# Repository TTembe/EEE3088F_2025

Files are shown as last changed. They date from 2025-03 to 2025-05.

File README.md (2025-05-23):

#  Micro-Mouse Power Subsystem – EEE3088F 2025

This repository contains the schematic, PCB layout, firmware, and documentation for the **Power Subsystem** of a maze-solving Micro-Mouse robot, developed as part of the EEE3088F course at the University of Cape Town.

---

##  Project Overview

This project focuses on the design, implementation, and testing of a compact and efficient **Power Subsystem** for a Micro-Mouse (MM) robot.

The power module is responsible for delivering regulated voltages, safe battery charging, motor power distribution, and real-time monitoring all within a space- and cost-constrained printed circuit board (PCB) footprint. It was developed to integrate seamlessly with the rest of the Micro-Mouse system, which includes processing, sensing, and control subsystems.

This subsystem ensures that all other modules in the robot receive stable power while providing built-in protection, control, and monitoring features. Its design includes features like dual-mode battery charging, USB-C PD negotiation, high-side switching for external loads, and I2C-based current/voltage sensing. 

The design adheres to the full set of requirements for the complete robot. The board is designed for manufacturability via JLCPCB and optimized for both performance and academic assessment.

---

##  Features

-  **Dual Motor Power Support**  
  Powers up to 4 brushed DC motors with reliable bidirectional control  including two high-current auxiliary motors (500mA each).

-  **Intelligent Battery Charging**  
  Automatically charges a single-cell LiPo battery from a 9V input using a selectable current mode: safe slow charge (~200mA) or faster charging (~600mA ±100mA).

-  **Real-Time Power Monitoring**  
  Monitors battery voltage and current in real-time using the INA219 sensor connected to the I²C bus, enabling diagnostics and data logging.

-  **USB-C Power Delivery Integration**  
  Negotiates 9V from compliant USB-C PD sources via the CH224K controller to support flexible charging and system power input.

-  **External Load Control**  
  Includes two high-side load switches for driving external 5V peripherals up to 1A each, with control via GPIO from the main processor.

-  **Precision Voltage Regulation**  
  Provides clean and accurate 3.3V (±5%) and 5V (±5%) rails for digital logic and sensor subsystems, supporting peak currents of up to 1.5A.

-  **Efficient Power Switching**  
  Features a physical ON/OFF switch that disables both 3.3V and 5V rails when inactive, reducing standby battery draw to under 30μA.

-  **Compact PCB Footprint**  
  Fully integrated on a compact 82mm × 60mm 2-layer PCB, designed for modular stacking with the micro-mouse system.

-  **Cost-Effective Design**  
  Uses carefully selected components and efficient routing to stay well within the \$70 total budget limit for the project.

---

## Repository Structure

```bash
├── hardware/
│   ├── PCB_KiCad/             # Schematic and PCB layout (KiCad)
│   ├── Gerber_Files/          # JLCPCB-ready fabrication files
│   └── BOM/                   # Bill of Materials (.xlsx and .tex)
│
├── firmware/
│   ├── PowerControl/          # Firmware for fast charge control via PB4
│   └── INA219_Test/           # Firmware to read INA219 values via I2C
│
├── test_procedures/
│   └── ATP_Documents/         # Detailed Acceptance Test Procedures
│
├── docs/
│   ├── Report_Final.pdf       # Final academic report
│   └── Images/                # System diagrams, PCB renders
│
└── README.md

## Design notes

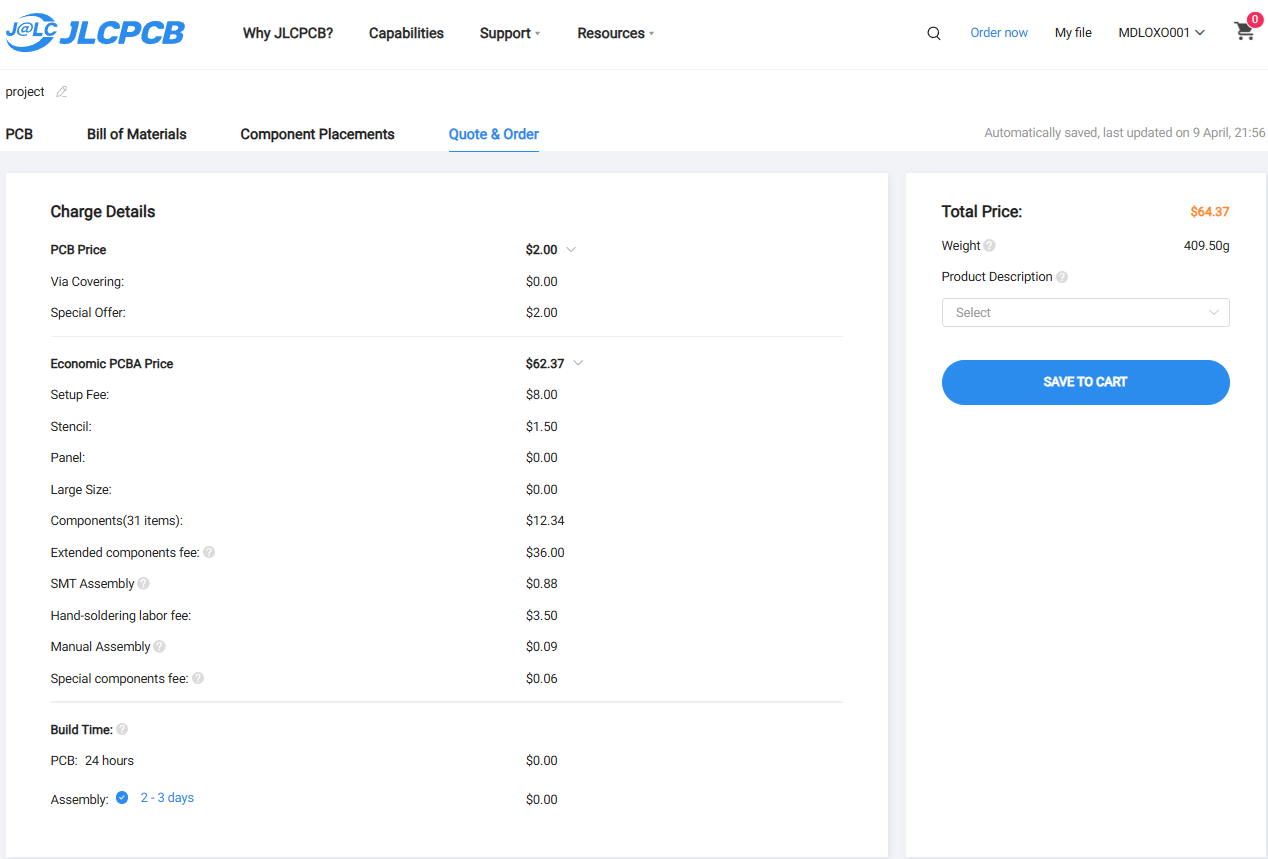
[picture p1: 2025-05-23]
EEE3088F_Project_JLCPCBACCEPTANCE_TMBTLA001_MDLOXO001.png.png

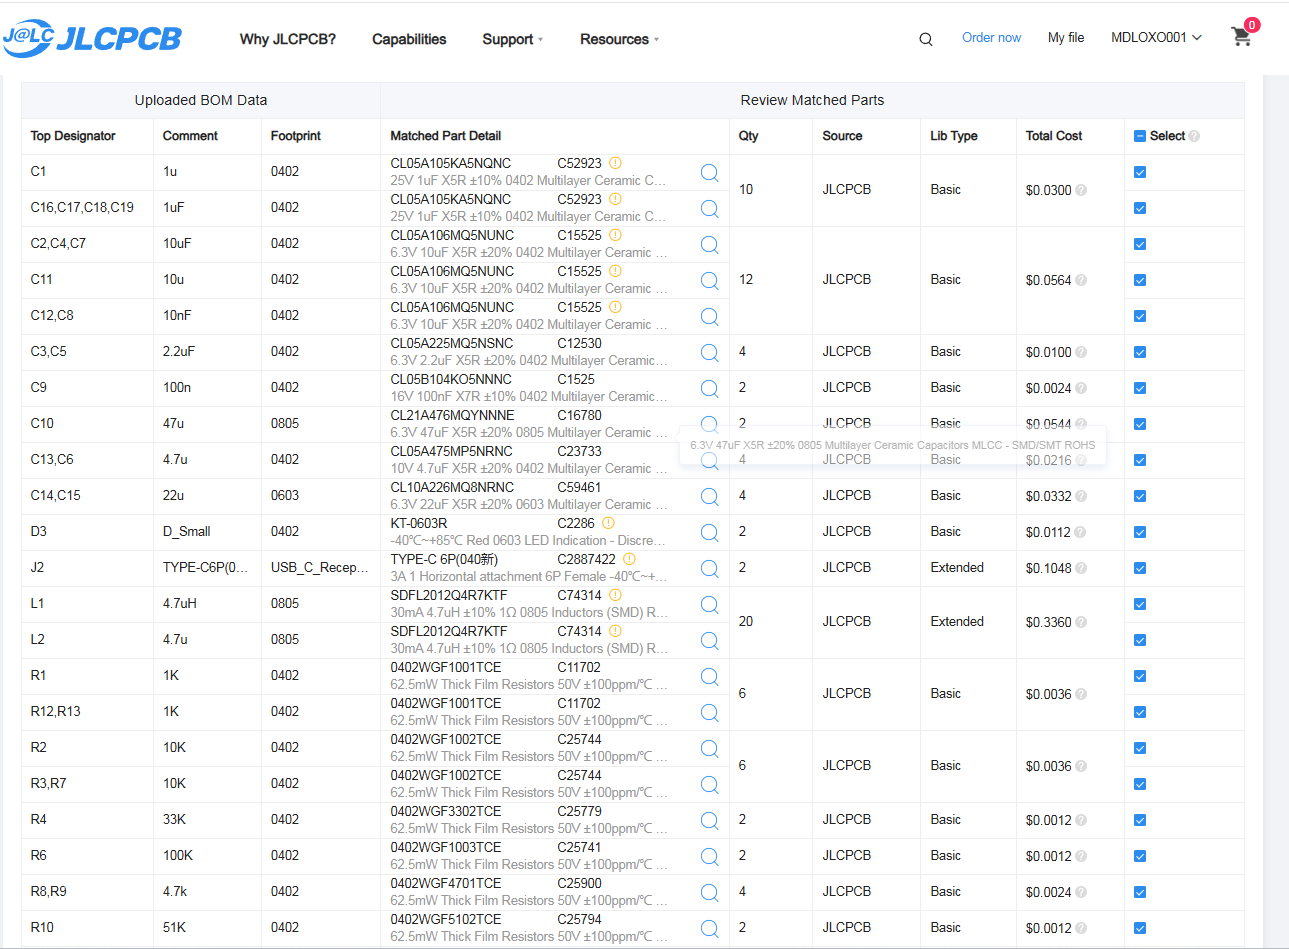
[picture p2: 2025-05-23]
EEE3088F_Project_JLCPCBBOM_TMBTLA001_MDLOXO001.png

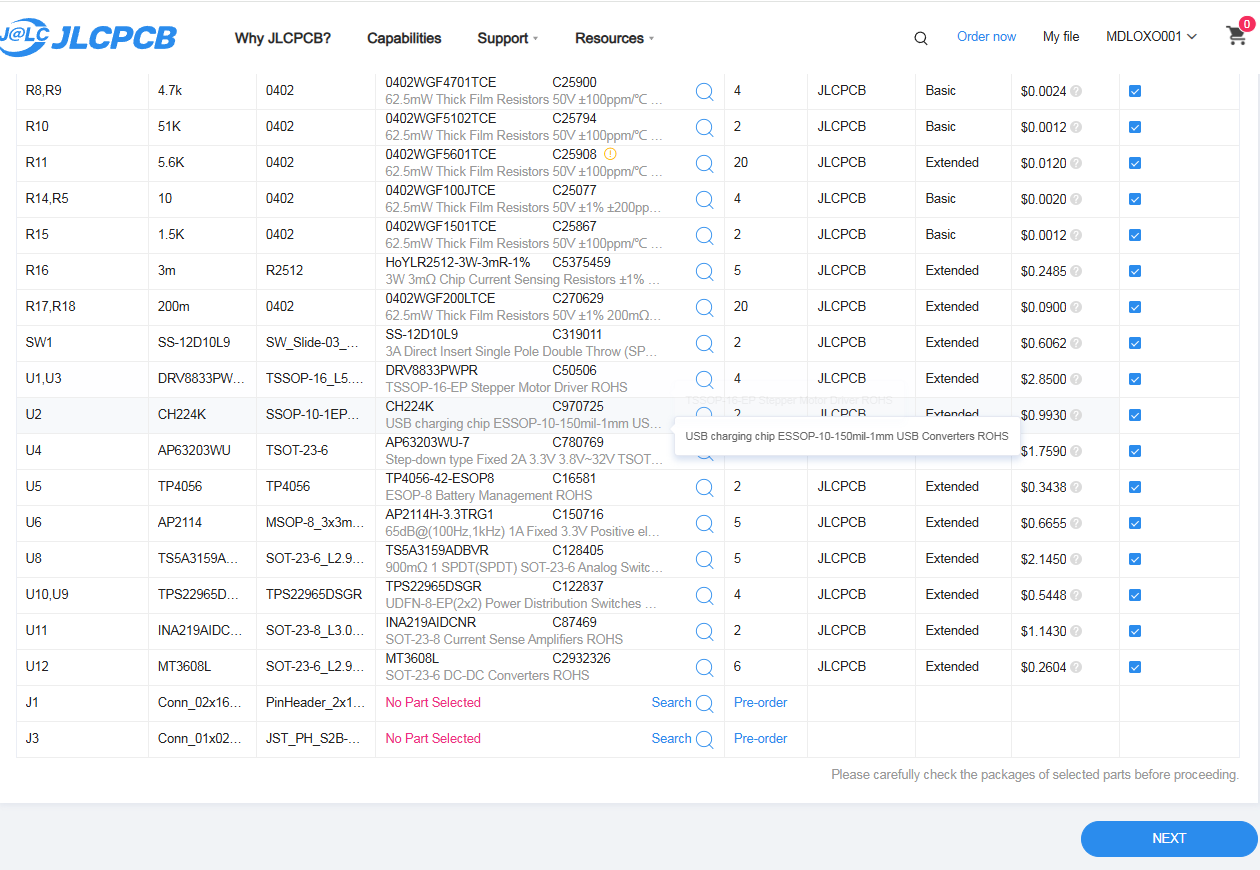
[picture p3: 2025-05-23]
EEE3088F_Project_JLCPCBBOM_TMBTLA001_MDLOXO001 (2).png

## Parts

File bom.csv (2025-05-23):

Designator | Footprint | Quantity | Value | LCSC Part #
C1 | 0402 | 1 | 1u | C52923
C10 | 0805 | 1 | 47u | C16780
C11 | 0402 | 1 | 10u | C15525
C12, C8 | 0402 | 2 | 10nF | C15525
C13, C6 | 0402 | 2 | 4.7u | C23733
C14, C15 | 0603 | 2 | 22u | C59461
C16, C17, C18, C19 | 0402 | 4 | 1uF | C52923
C2, C4, C7 | 0402 | 3 | 10uF | C15525
C3, C5 | 0402 | 2 | 2.2uF | C12530
C9 | 0402 | 1 | 100n | C1525
D3 | 0402 | 1 | D_Small | C2286
J1 | PinHeader_2x16_P2.54mm_Vertical | 1 | Conn_02x16_Odd_Even
J2 | USB_C_Receptacle_GCT_USB4135-GF-A_6P_TopMnt_Horizontal | 1 | TYPE-C 6P(040新) | C2887422
J3 | JST_PH_S2B-PH-K_1x02_P2.00mm_Horizontal | 1 | Conn_01x02_Pin
JP1, JP2, JP3, JP4 | SolderJumper-2_P1.3mm_Open_RoundedPad1.0x1.5mm | 4 | Jumper_2_Open
L1 | 0805 | 1 | 4.7uH | C74314
L2 | 0805 | 1 | 4.7u | C74314
R1 | 0402 | 1 | 1K | C11702
R10 | 0402 | 1 | 51K | C25794
R11 | 0402 | 1 | 5.6K
R12, R13 | 0402 | 2 | 1K | C11702
R14, R5 | 0402 | 2 | 10 | C25077
R15 | 0402 | 1 | 1.5K | C25867
R16 | R2512 | 1 | 3m | C5375459
R17, R18 | 0402 | 2 | 200m | C270629
R2 | 0402 | 1 | 10K | C25744
R3, R7 | 0402 | 2 | 10K | C25744
R4 | 0402 | 1 | 33K | C25779
R6 | 0402 | 1 | 100K | C25741
R8, R9 | 0402 | 2 | 4.7k | C25900
SW1 | SW_Slide-03_Wuerth-WS-SLTV_10x2.5x6.4_P2.54mm | 1 | SS-12D10L9 | C319011
TP1, TP10, TP11, TP12, TP13, TP14, TP2, TP3, TP5, TP6, TP7, TP8, TP9 | TestPoint_Pad_D2.0mm | 13 | TestPoint
U1, U3 | TSSOP-16_L5.0-W4.4-P0.65-LS6.4-BL-EP | 2 | DRV8833PWPR | C50506
U10, U9 | TPS22965DSGR | 2 | TPS22965DSGR | C122837
U11 | SOT-23-8_L3.0-W1.7-P0.65-LS2.8-BR | 1 | INA219AIDCNR | C87469
U12 | SOT-23-6_L2.9-W1.6-P0.95-LS2.8-BL_3 | 1 | MT3608L | C2932326
U2 | SSOP-10-1EP_3.9x4.9mm_P1mm_EP2.1x3.3mm | 1 | CH224K | C970725
U4 | TSOT-23-6 | 1 | AP63203WU | C780769
U5 | TP4056 | 1 | TP4056 | C16581
U6 | MSOP-8_3x3mm_P0.65mm | 1 | AP2114 | C150716
U8 | SOT-23-6_L2.9-W1.6-P0.95-LS2.8-BR | 1 | TS5A3159ADBVR | C128405

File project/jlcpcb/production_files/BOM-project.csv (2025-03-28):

Comment | Designator | Footprint | LCSC | Quantity
0.5m | R16 | R_Axial_Shunt_L22.2mm_W8.0mm_PS14.30mm_P25.40mm | C105052 | 1
1K | R12,R13 | R_0402_1005Metric_Pad0.72x0.64mm_HandSolder | C11702 | 2
TPS22965DSGR | U10,U9 | TPS22965DSGR | C122837 | 2
2.2uF | C3,C5 | C_0402_1005Metric_Pad0.74x0.62mm_HandSolder | C12530 | 2
TS5A3159ADBVR | U11 | SOT-23-6 | C128405 | 1
AP2114 | U6 | MSOP-8_3x3mm_P0.65mm | C150716 | 1
100n | C9 | C_0402_1005Metric_Pad0.74x0.62mm_HandSolder | C1525 | 1
10u | C11,C12,C2,C4,C7,C8 | C_0402_1005Metric_Pad0.74x0.62mm_HandSolder | C15525 | 6
TP4056 | U5 | TP4056 | C16581 | 1
47u | C10 | C_0805_2012Metric_Pad1.18x1.45mm_HandSolder | C16780 | 1
D_Small | D3 | D_0402_1005Metric_Pad0.77x0.64mm_HandSolder | C2286 | 1
100K | R6 | R_0402_1005Metric_Pad0.72x0.64mm_HandSolder | C25741 | 1
10k | R14,R3,R5,R7 | R_0402_1005Metric_Pad0.72x0.64mm_HandSolder | C25744 | 4
33K | R4 | R_0402_1005Metric_Pad0.72x0.64mm_HandSolder | C25779 | 1
1.5K | R15 | R_0402_1005Metric_Pad0.72x0.64mm_HandSolder | C25867 | 1
4.7k | R8,R9 | R_0402_1005Metric_Pad0.72x0.64mm_HandSolder | C25900 | 2
TYPE-C 6P(040新) | J2 | USB_C_Receptacle_GCT_USB4135-GF-A_6P_TopMnt_Horizontal | C2887422 | 1
MT3608L | U7 | WSON-6-1EP_2x2mm_P0.65mm_EP1x1.6mm | C2932326 | 1
SS-12D10L9 | SW1 | SW_Slide-03_Wuerth-WS-SLTV_10x2.5x6.4_P2.54mm | C319011 | 1
DRV8833PWPR | U1,U3 | DRV8833PWPR | C50506 | 2
1u | C1,C16,C17 | C_0402_1005Metric_Pad0.74x0.62mm_HandSolder | C52923 | 3
22u | C14,C15 | C_0603_1608Metric_Pad1.08x0.95mm_HandSolder | C59461 | 2
4.7uH | L1,L2 | L_0805_2012Metric_Pad1.05x1.20mm_HandSolder | C74314 | 2
AP63203WU | U4 | TSOT-23-6 | C780769 | 1
INA219AIDCNR | U8 | INA219AIDCNR | C87469 | 1
CH224K | U2 | SSOP-10-1EP_3.9x4.9mm_P1mm_EP2.1x3.3mm | C970725 | 1
Jumper_2_Open | JP2 | SolderJumper-2_P1.3mm_Open_RoundedPad1.0x1.5mm |  | 1
Jumper_2_Open | JP4 | SolderJumper-2_P1.3mm_Open_RoundedPad1.0x1.5mm |  | 1
Jumper_2_Open | JP3 | SolderJumper-2_P1.3mm_Open_RoundedPad1.0x1.5mm |  | 1
Jumper_2_Open | JP1 | SolderJumper-2_P1.3mm_Open_RoundedPad1.0x1.5mm |  | 1
5.6K | R11 | R_0402_1005Metric_Pad0.72x0.64mm_HandSolder |  | 1
51K | R10 | R_0402_1005Metric_Pad0.72x0.64mm_HandSolder |  | 1
TestPoint | TP5 | TestPoint_Pad_D2.0mm |  | 1
TestPoint | TP6 | TestPoint_Pad_D2.0mm |  | 1
TestPoint | TP9 | TestPoint_Pad_D2.0mm |  | 1
TestPoint | TP1 | TestPoint_Pad_D2.0mm |  | 1
1K | R1 | R_0402_1005Metric_Pad0.72x0.64mm_HandSolder |  | 1
TestPoint | TP11 | TestPoint_Pad_D2.0mm |  | 1
TestPoint | TP7 | TestPoint_Pad_D2.0mm |  | 1
TestPoint | TP14 | TestPoint_Pad_D2.0mm |  | 1
TestPoint | TP2 | TestPoint_Pad_D2.0mm |  | 1
4.7u | C13 | C_0402_1005Metric_Pad0.74x0.62mm_HandSolder |  | 1
TestPoint | TP10 | TestPoint_Pad_D2.0mm |  | 1
Conn_01x02_Pin | J3 | PinHeader_1x02_P2.00mm_Vertical |  | 1
TestPoint | TP8 | TestPoint_Pad_D2.0mm |  | 1
10K | R2 | R_0402_1005Metric_Pad0.72x0.64mm_HandSolder |  | 1
TestPoint | TP12 | TestPoint_Pad_D2.0mm |  | 1
Conn_02x16_Odd_Even | J1 | PinHeader_2x16_P2.54mm_Vertical |  | 1
TestPoint | TP13 | TestPoint_Pad_D2.0mm |  | 1
4.7u | C6 | C_0402_1005Metric_Pad0.74x0.62mm_HandSolder |  | 1

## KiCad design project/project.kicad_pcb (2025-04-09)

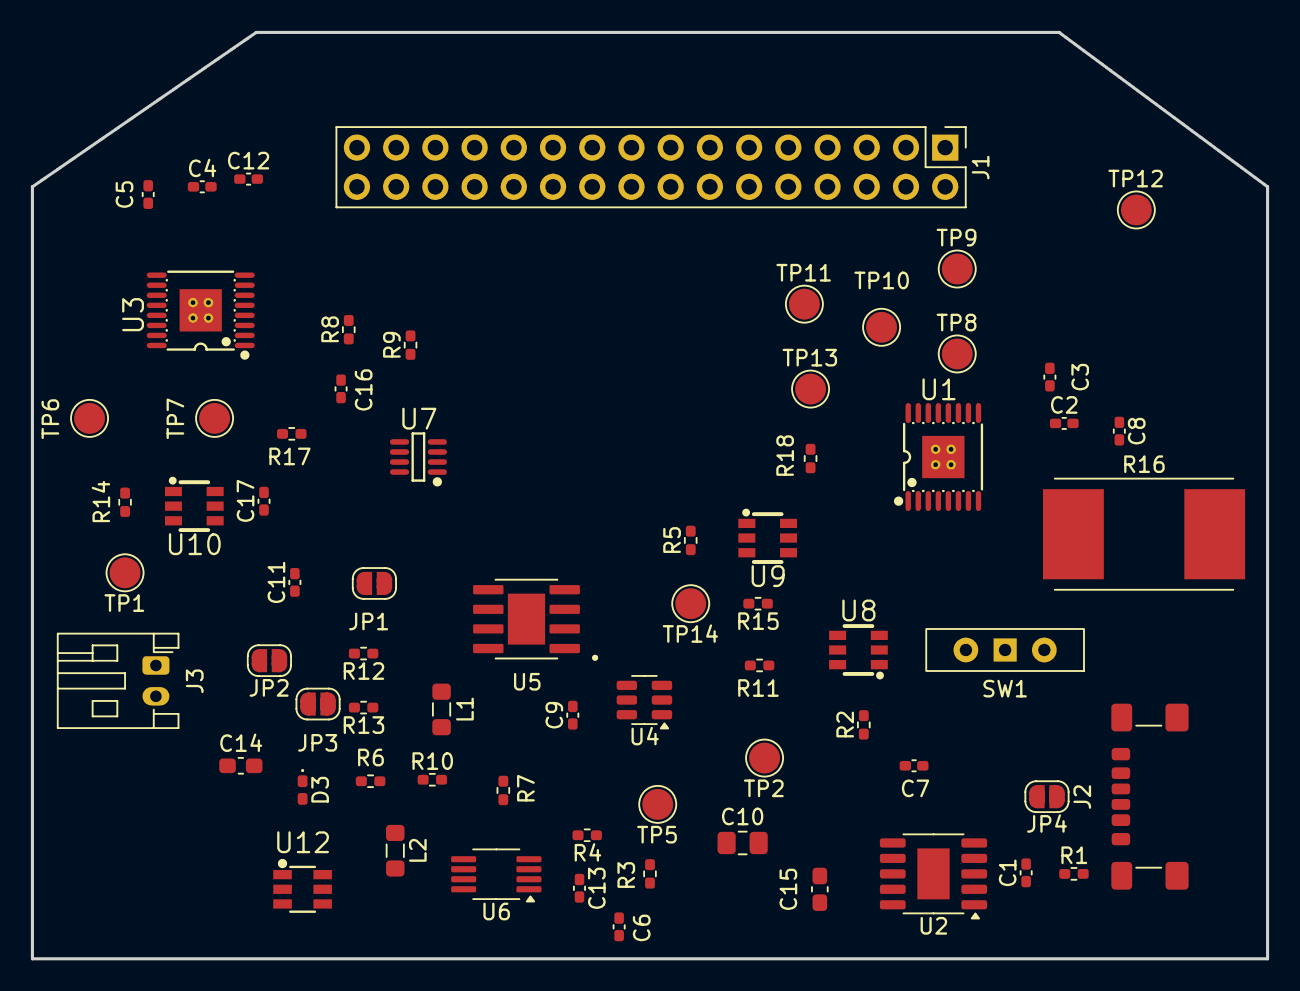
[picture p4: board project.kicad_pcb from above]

Board: 2 copper layers, 80.0 x 60.0 mm, 69 parts (0 on the bottom side), 57 nets, no tracks yet.

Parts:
C1: 1u; C_0402_1005Metric_Pad0.74x0.62mm_HandSolder
C2, C4, C7: 10uF; C_0402_1005Metric_Pad0.74x0.62mm_HandSolder
C3, C5: 2.2uF; C_0402_1005Metric_Pad0.74x0.62mm_HandSolder
C6, C13: 4.7u; C_0402_1005Metric_Pad0.74x0.62mm_HandSolder
C8, C12: 10nF; C_0402_1005Metric_Pad0.74x0.62mm_HandSolder
C9: 100n; C_0402_1005Metric_Pad0.74x0.62mm_HandSolder
C10: 47u; C_0805_2012Metric_Pad1.18x1.45mm_HandSolder
C11: 10u; C_0402_1005Metric_Pad0.74x0.62mm_HandSolder
C14, C15: 22u; C_0603_1608Metric_Pad1.08x0.95mm_HandSolder
C16, C17: 1uF; C_0402_1005Metric_Pad0.74x0.62mm_HandSolder
D3: D_Small; D_0402_1005Metric_Pad0.77x0.64mm_HandSolder
J1: Conn_02x16_Odd_Even; PinHeader_2x16_P2.54mm_Vertical
J2: TYPE-C 6P(040新); USB_C_Receptacle_GCT_USB4135-GF-A_6P_TopMnt_Horizontal
J3: Conn_01x02_Pin; JST_PH_S2B-PH-K_1x02_P2.00mm_Horizontal
JP1, JP2, JP3, JP4: Jumper_2_Open; SolderJumper-2_P1.3mm_Open_RoundedPad1.0x1.5mm
L1: 4.7uH; L_0805_2012Metric_Pad1.05x1.20mm_HandSolder
L2: 4.7u; L_0805_2012Metric_Pad1.05x1.20mm_HandSolder
R1, R12, R13: 1K; R_0402_1005Metric_Pad0.72x0.64mm_HandSolder
R2, R3, R7: 10K; R_0402_1005Metric_Pad0.72x0.64mm_HandSolder
R4: 33K; R_0402_1005Metric_Pad0.72x0.64mm_HandSolder
R5, R14: 10k; R_0402_1005Metric_Pad0.72x0.64mm_HandSolder
R6: 100K; R_0402_1005Metric_Pad0.72x0.64mm_HandSolder
R8, R9: 4.7k; R_0402_1005Metric_Pad0.72x0.64mm_HandSolder
R10: 51K; R_0402_1005Metric_Pad0.72x0.64mm_HandSolder
R11: 5.6K; R_0402_1005Metric_Pad0.72x0.64mm_HandSolder
R15: 1.5K; R_0402_1005Metric_Pad0.72x0.64mm_HandSolder
R16: 0.5m; R_Shunt_Vishay_WSR2_WSR3
R17, R18: 200m; R_0402_1005Metric_Pad0.72x0.64mm_HandSolder
SW1: SS-12D10L9; SW_Slide-03_Wuerth-WS-SLTV_10x2.5x6.4_P2.54mm
TP1, TP2, TP5, TP6, TP7, TP8, TP9, TP10, TP11, TP12, TP13, TP14: TestPoint; TestPoint_Pad_D2.0mm
U1, U3: DRV8833PWPR; TSSOP-16_L5.0-W4.4-P0.65-LS6.4-BL-EP
U2: CH224K; SSOP-10-1EP_3.9x4.9mm_P1mm_EP2.1x3.3mm
U4: AP63203WU; TSOT-23-6
U5: TP4056
U6: AP2114; MSOP-8_3x3mm_P0.65mm
U7: INA219AIDCNR; SOT-23-8_L3.0-W1.7-P0.65-LS2.8-BR
U8: TS5A3159ADBVR; SOT-23-6_L2.9-W1.6-P0.95-LS2.8-BR
U9, U10: TPS22965DSGR; SOT-23-6_L2.9-W1.6-P0.95-LS2.8-BR
U12: MT3608L; SOT-23-6_L2.9-W1.6-P0.95-LS2.8-BL_3

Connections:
/3V3 Out: C13.1, J1.18, R4.1, R8.1, R9.1, U6.3 (OUT), U7.4 (VS), U7.8 (A1)
/5V Out: C14.1, C16.1, C17.1, D3.1 (K), J1.20, R6.1, U8.5 (V+), U9.1 (VIN), U9.2 (VIN), U9.4 (VBIAS), U10.1 (VIN), U10.2 (VIN), U10.4 (VBIAS)
/BATT: J3.1, JP1.1 (A), R16.1, SW1.3 (A), TP2.1, U5.5 (BAT)
/Battery: C1.1, C2.2, C4.2, C6.1, C8.1, C12.1, C15.1, J1.14, L2.1, R1.1, SW1.1 (B), U1.1 (NSLEEP), U1.12 (VM), U2.1 (VDD), U3.1 (NSLEEP), U3.12 (VM), U6.1 (EN), U6.2 (IN), U12.4 (EN), U12.5 (VIN)
/CTRL_EXT_LOAD1: J1.25, U10.3 (ON)
/CTRL_EXT_LOAD2: J1.7, U9.3 (ON)
/EXT_LOAD1_OUT: J1.21, R14.1, TP1.1
/EXT_LOAD2_OUT: J1.11, R5.1, TP14.1
/FAST_CHARGE_CTRL: J1.13, U8.6 (IN)
/HV: C7.1, J1.22, U4.2 (EN), U4.3 (IN)
/I2C1_SCL: J1.16, R8.2, U7.5 (SCL)
/I2C1_SDA: J1.17, R9.2, U7.6 (SDA)
/MOTOR1_A_OUT: J1.32, TP10.1, U1.2 (AOUT1)
/MOTOR1_B_OUT: J1.31, TP11.1, U1.4 (AOUT2)
/MOTOR1_CTRL1: J1.28, U1.16 (AIN1)
/MOTOR1_CTRL2: J1.30, U1.15 (AIN2)
/MOTOR2_A_OUT: J1.2, TP12.1, U1.7 (BOUT1)
/MOTOR2_B_OUT: J1.1, TP13.1, U1.5 (BOUT2)
/MOTOR2_CTRL1: J1.4, U1.9 (BIN1)
/MOTOR2_CTRL2: J1.6, U1.10 (BIN2)
/MOTOR3_A_OUT: J1.27, TP6.1, U3.2 (AOUT1)
/MOTOR3_B_OUT: J1.29, TP7.1, U3.4 (AOUT2)
/MOTOR3_CTRL1: J1.24, U3.16 (AIN1)
/MOTOR3_CTRL2: J1.26, U3.15 (AIN2)
/MOTOR4_A_OUT: J1.3, TP8.1, U3.7 (BOUT1)
/MOTOR4_B_OUT: J1.5, TP9.1, U3.5 (BOUT2)
/MOTOR4_CTRL1: J1.8, U3.9 (BIN1)
/MOTOR4_CTRL2: J1.10, U3.10 (BIN2)
GND: C1.2, C2.1, C3.1, C4.1, C5.1, C6.2, C7.2, C10.2, C11.2, C13.2, C14.2, C15.2, C16.2, C17.2, J1.19, J1.23, J2.A12 (GND), J2.B12 (GND), J2.S1 (SHIELD), J3.2, R3.2, R5.2, R7.2, R10.2, R11.2, R14.2, R15.1, R17.2, R18.2, U1.13 (GND), U1.17 (EXP), U2.2 (CFG2), U2.3 (CFG3), U2.9 (CFG1), U2.11 (GND), U3.13 (GND), U3.17 (EXP), U4.4 (GND), U5.1 (TEMP), U5.3 (GND), U6.5 (GND), U6.6 (GND), U6.7 (GND), U6.8 (GND), U7.3 (GND), U7.7 (A0), U8.2 (GND), U9.5 (GND), U10.5 (GND), U12.2 (GND)
unnamed: D3.2 (A), L2.2, U12.1 (SW)
unnamed: J2.A5 (CC1), U2.7 (CC1)
unnamed: J2.B5 (CC2), U2.6 (CC2)
unnamed: J2.A9 (VBUS), J2.B9 (VBUS), R1.2, R2.2
unnamed: C11.1, JP1.2 (B)
unnamed: JP2.1 (A), R12.1
unnamed: C10.1, JP2.2 (B), JP3.1 (A), L1.2, TP5.1, U4.1 (FB), U5.4 (VCC), U5.8 (CE)
unnamed: JP3.2 (B), R13.1
unnamed: JP4.1 (A), U2.4 (DP)
unnamed: JP4.2 (B), U2.5 (DM)
unnamed: R18.1, U1.3 (AISEN), U1.6 (BISEN)
unnamed: C8.2, U1.11 (VCP)
unnamed: C3.2, U1.14 (VINT)
unnamed: R2.1, U2.8 (VBUS)
unnamed: R17.1, U3.3 (AISEN), U3.6 (BISEN)
unnamed: C12.2, U3.11 (VCP)
unnamed: C5.2, U3.14 (VINT)
unnamed: C9.1, U4.6 (BST)
unnamed: C9.2, L1.1, U4.5 (SW)
unnamed: U5.2 (PROG), U8.4 (COM)
unnamed: R13.2, U5.7 (~CHRG)
unnamed: R12.2, U5.6 (~STDBY)
unnamed: R3.1, R4.2, U6.4 (ADJ)
unnamed: R16.2, U7.1 (IN+)
unnamed: R15.2, U8.3 (NC)
unnamed: R11.1, U8.1 (NO)
unnamed: R6.2, R7.1, U12.3 (FB)
unnamed: R10.1, U12.6 (OC)

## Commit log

2025-03-26 USB and PD circuit
2025-03-26 Add switching circuits
2025-03-26 changed pull up resistor values
    [project.kicad_sch]
2025-03-27 change resistor
    [project.kicad_sch]
2025-03-27 add Oxolo subsections
    [project.kicad_sch]
2025-03-27 changed batt
    [project.kicad_sch]
2025-03-27 another update
    [project.kicad_sch]
2025-03-27 Step down voltage regulator
    [project.kicad_sch]
2025-03-27 Step up voltage regulation
    [project.kicad_sch]
2025-03-27 Assigning LCSC
    [project.kicad_sch]
2025-03-27 assign footprint
2025-03-27 Corrected LCSC
    [project.kicad_sch]
2025-03-27 CHANGED RESISTOR VALUE
    [project.kicad_sch]
2025-03-28 Footprints updated
    [project.kicad_sch]
2025-03-28 footprint assignment
    [project.kicad_sch]
2025-04-08 Updates
    Changes datasheet names,updates PCB,fixex errors
    [project.kicad_pcb]
2025-04-08 fixing errors on PCB
    [project.kicad_pcb, project.kicad_sch]
2025-04-08 assigning correct footprints
    [project.kicad_sch]
